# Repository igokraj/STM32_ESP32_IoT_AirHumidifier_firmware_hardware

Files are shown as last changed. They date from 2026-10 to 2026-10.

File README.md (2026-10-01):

# STM32 + ESP32 IoT (AWS Core) Air Humidifier

Projekt zakładał stworzenie sterownika nawilżacza powietrza opartego na dwóch mikrokontrolerach STM32F446RE oraz ESP32-S3. STM32 odpowiada za sterowanie wentylatorem sygnałem PWM, obsługę czujników oraz maszynę stanów, na której opiera się działanie systemu. ESP32 służy wyłącznie do połączenia urządzenia z Wi-Fi, a następnie chmurą AWS IoT Core (Amazon) poprzez protokół MQTT.

Oba mikrokontrolery komunikują się ze sobą przez UART, wymieniając wiadomości w formacie JSON. STM32 wysyła do ESP32 informacje o aktualnej wilgotności, stanie systemu, prędkości obrotowej wentylatora oraz progu wilgotności ustawionym przez użytkownika. ESP32 przekazuje do STM32 wiadomość JSON przygotowaną wcześniej przez użytkownika, zawierającą żądany próg wilgotności w pomieszczeniu (np. 60%) oraz żądaną prędkość wentylatora, wybieraną poziomami od 0 do 5. Każdy poziom odpowiada innemu wypełnieniu sygnału PWM.

Firmware na STM32 jest napisany w C++, natomiast ESP32 działa na FreeRTOS, który jest natywną częścią frameworka.

Projekt był testowany na płytce stykowej, bez rzeczywistego wentylatora. Pomiar prędkości obrotowej sprawdzałem za pomocą drugiego timera, który generował impulsy i był fizycznie połączony z wejściem timera zliczającego impulsy z wentylatora. Sterowanie wentylatorem testowałem na servo ze zmienionymi parametrami sygnału PWM, ale logika sterowania pozostała taka sama.

This is an air humidifier controller built around two microcontrollers: an STM32F446RE and an ESP32-S3. The STM32 does the actual work. It drives the fan with PWM, reads the sensors and runs the state machine the whole system is based on. The ESP32 has only one job: it connects to Wi-Fi and talks to AWS IoT Core over MQTT.

The two chips talk to each other over UART using JSON messages. The STM32 sends the current humidity, system state, fan RPM and the humidity target set by the user. The ESP32 sends back a JSON message from the user with the target room humidity (e.g. 60%) and the fan speed level, from 0 to 5. Each level is a different PWM duty cycle.

The STM32 firmware is written in C++. The ESP32 runs on FreeRTOS, which comes built into ESP-IDF.

I tested everything on a breadboard without a real fan. To check the RPM measurement, I used a second timer to generate pulses and wired it to the input of the timer that counts the fan pulses. For fan control I used a servo instead, with different PWM settings, but the control logic stayed the same.

## Photos

**Breadboard prototype**

<p align="center">
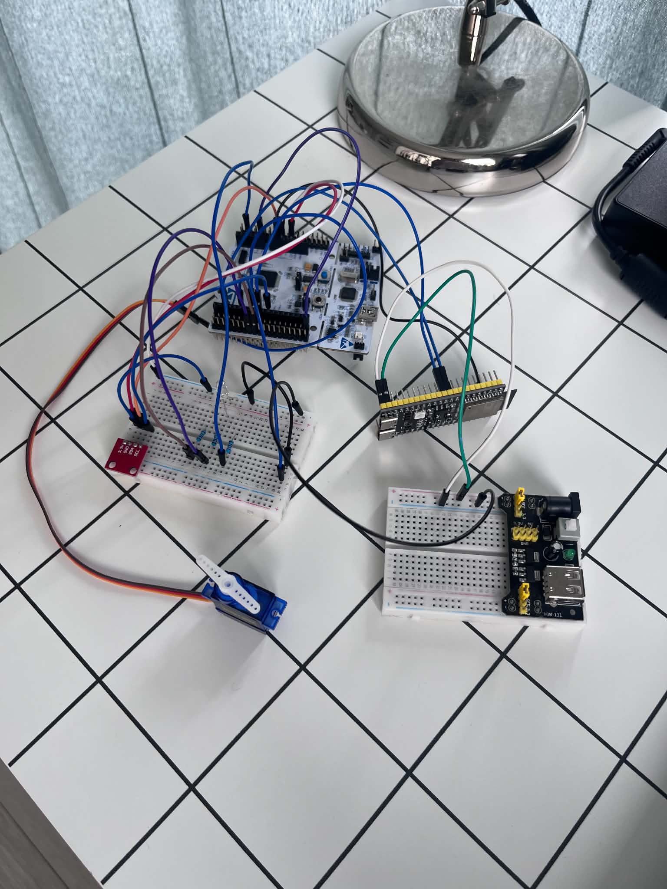
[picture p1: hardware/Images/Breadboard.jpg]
  
</p>

**Schematic**

<p align="center">
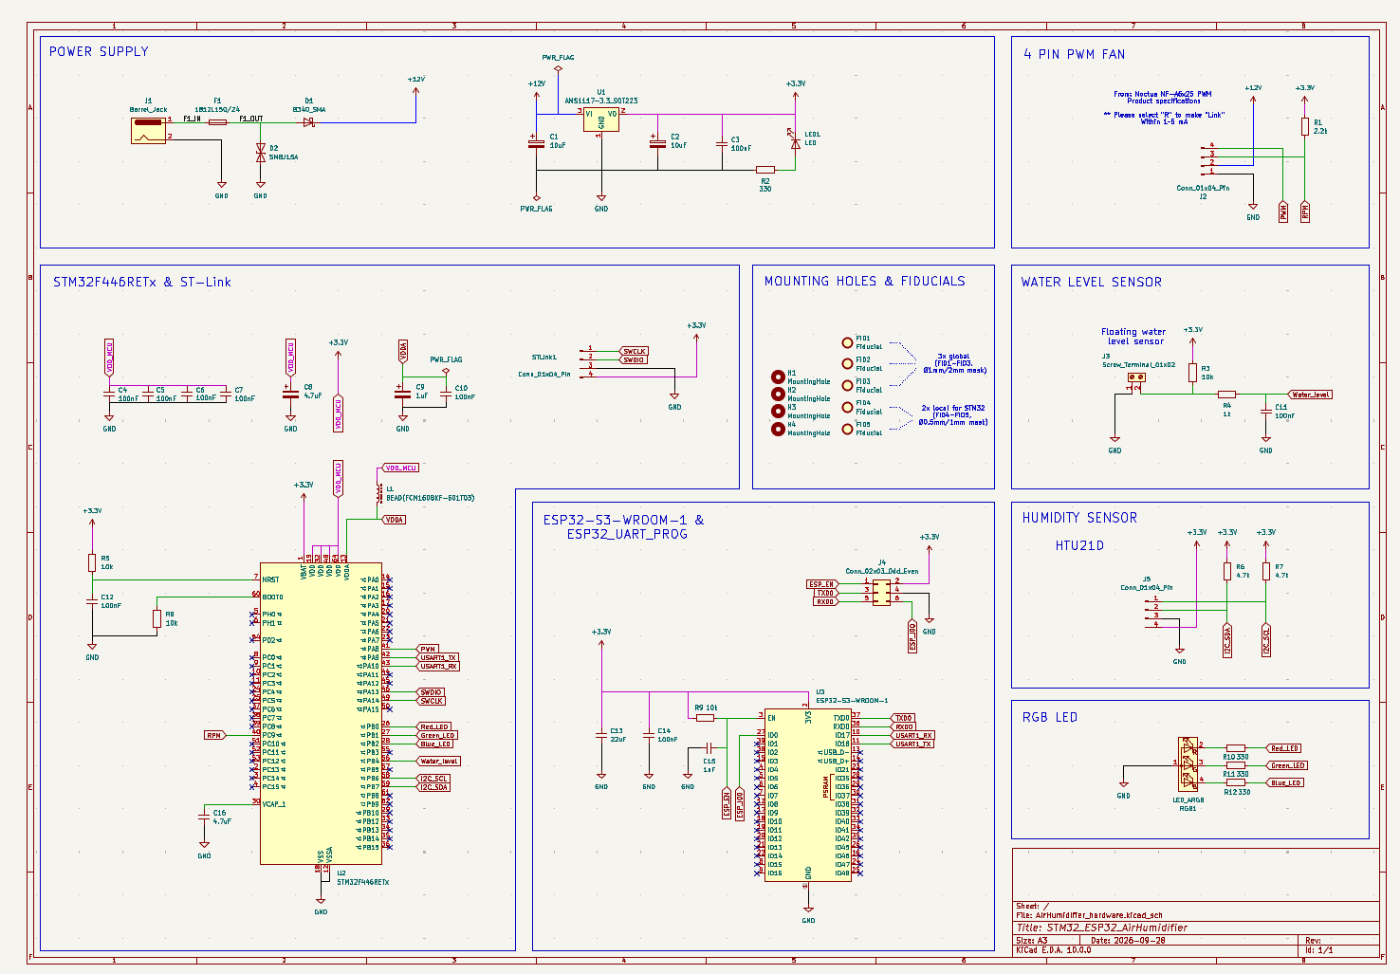
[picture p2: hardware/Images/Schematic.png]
  
</p>

**PCB layout and 3D render**

<p align="center">
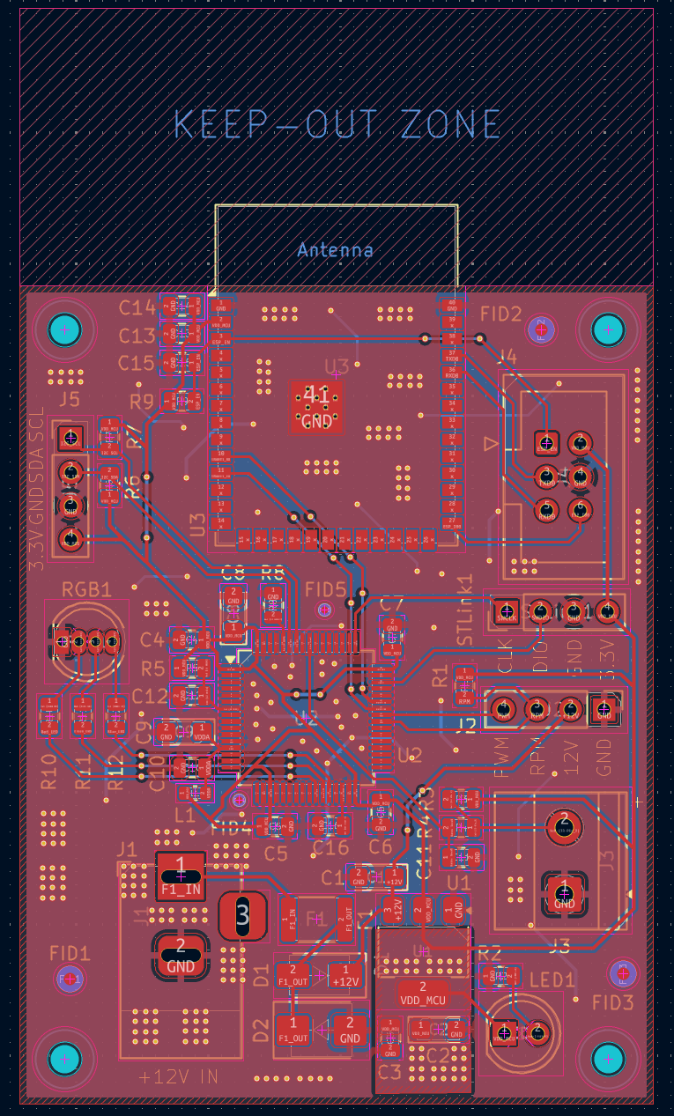
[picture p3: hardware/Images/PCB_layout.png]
  
  &nbsp;
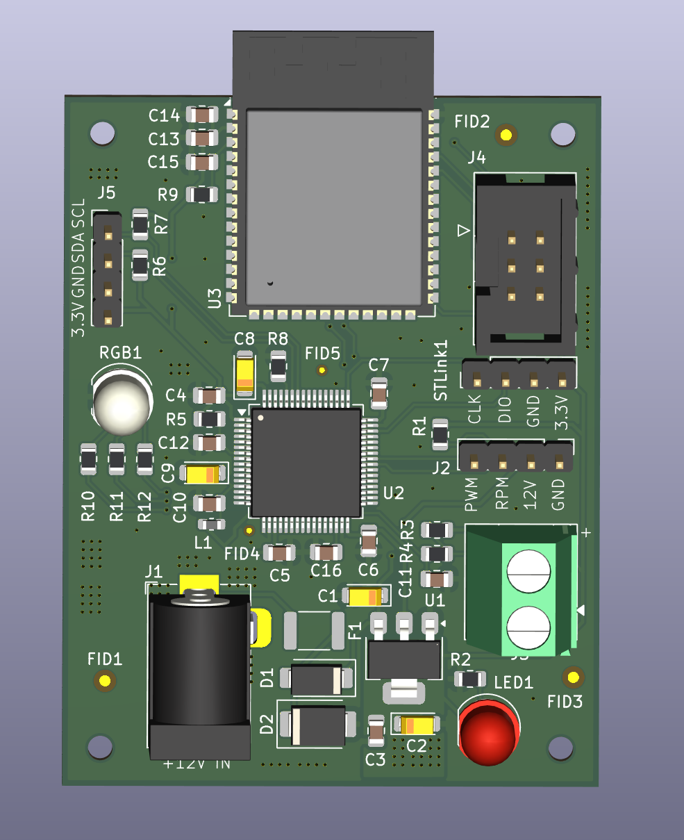
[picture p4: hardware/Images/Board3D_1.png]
  
</p>

<p align="center">
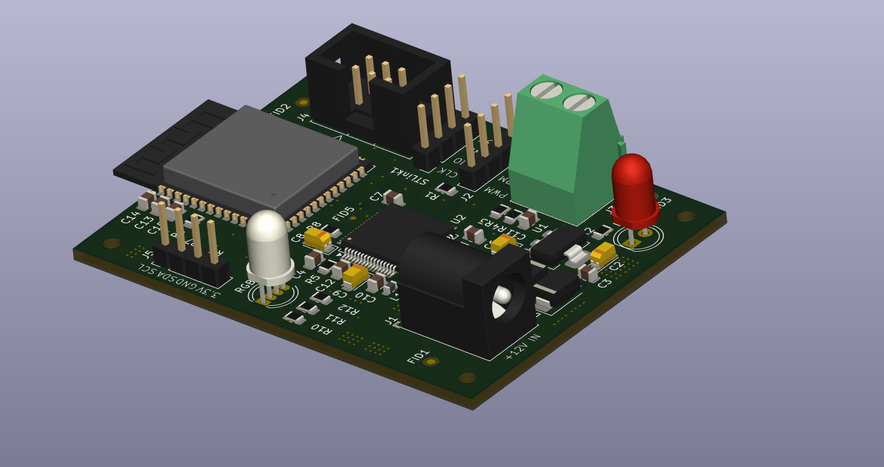
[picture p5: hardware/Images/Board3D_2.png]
  
</p>

## How it works

The system has four states: **Waiting**, **Running**, **EmptyContainer** (no water in the tank) and **Error**.

In the main loop the STM32:

1. checks for a JSON command from the ESP32 (`{"hum": 55, "rpm_lvl": 3}`) and updates the target humidity and fan speed level,
2. reads humidity from the HTU21D every 1 s. After 3 failed reads in a row it resets the I2C bus and goes into Error,
3. reads the water level sensor (float switch),
4. sets the state. Priority: sensor fault, then empty tank, then humidity below target,
5. drives the fan (PWM) and the RGB LED (green: running, blue: empty tank, red: error),
6. every 10 s sends a status message to the ESP32, for example `{"CurrentHumidity":48.20,"SetHum":70.00,"Status":1,"RPM":2000}`.

Fan speed has 6 levels (0 to 5, which means 0 to 100% PWM). The real RPM is measured from the fan's tachometer output using timer input capture. The watchdog (IWDG) resets the MCU if the program hangs.

The ESP32 passes messages between UART (115200 baud) and MQTT (TLS):

- publishes to `humidifier/<client_id>/data`
- subscribes to `humidifier/<client_id>/cmd` (only valid JSON is sent on to the STM32)

## Peripherals / electronics

- **STM32F446RETx**: main microcontroller
- **ESP32-S3-WROOM-1**: Wi-Fi / MQTT module
- **HTU21D**: humidity sensor (I2C)
- **4-pin PWM fan** (PC fan, e.g. Noctua NF-A6x25 PWM): 12 V, PWM and tachometer
- **Water level sensor** (float switch)
- **RGB LED**: shows the system state
- **AMS1117-3.3**: 3.3 V voltage regulator
- 12 V power connector (barrel jack) with a fuse, reverse polarity diode and TVS overvoltage protection
- SWD connector (ST-Link) for the STM32 and UART/boot header for programming the ESP32

## BOM (short version)

| Reference | Component | Qty |
| --- | --- | --- |
| U2 | STM32F446RETx | 1 |
| U3 | ESP32-S3-WROOM-1 | 1 |
| U1 | AMS1117-3.3 (3.3 V regulator) | 1 |
| RGB1 | RGB LED | 1 |
| LED1 | LED (power indicator) | 1 |
| J1 | Power jack (barrel jack) | 1 |
| J2 | 4-pin PWM fan connector | 1 |
| J3 | Screw terminal (water level sensor) | 1 |
| J4 | ESP32 programming header | 1 |
| J5 | HTU21D connector | 1 |
| STLink1 | STM32 programmer connector | 1 |
| F1 | Fuse | 1 |
| D1 | Schottky diode B340 (reverse polarity protection) | 1 |
| D2 | TVS diode SMBJ15A (overvoltage protection) | 1 |
| L1 | Ferrite bead (power filtering) | 1 |
| R, C | Resistors and capacitors (filtering, pull-up/down) | ~28 |

The full list (with LCSC part numbers) is in `AirHumidifier/hardware/BOM.xlsx` and `All_BOM.csv`.

## Firmware

**STM32**: written in **C++** on top of the C code generated by STM32CubeMX/HAL. The humidifier state logic, humidity sensor, UART, JSON parser and I2C bus recovery are separate classes/modules. The rest (GPIO, I2C, timers, UART, watchdog) is generated HAL code.

**ESP32**: written in **C** with ESP-IDF (FreeRTOS), split into `WIFI`, `UART` and `MQTT` modules. To build it you have to add your own `main/secrets.h` (Wi-Fi credentials, AWS endpoint and client ID) and AWS IoT certificates in `main/Cert/`. They are not included in the repo.

## Repo structure

- `AirHumidifier/firmware/stm32/`: CMake project with the STM32 sources
- `AirHumidifier/firmware/esp32/`: ESP-IDF project for the ESP32
- `AirHumidifier/hardware/`: KiCad schematic and PCB, production files (Gerbers), BOM
- `AirHumidifier/hardware/Images/`: schematic and PCB renders

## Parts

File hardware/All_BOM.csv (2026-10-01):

Reference | Qty | Value | DNP | Exclude from BOM | Exclude from Board | Footprint | Datasheet
C1,C2 | 2 | 10uF |  |  |  | Capacitor_Tantalum_SMD:CP_EIA-3216-18_Kemet-A
C3,C4,C5,C6,C7,C10,C11,C12,C14 | 9 | 100nF |  |  |  | Capacitor_SMD:C_0805_2012Metric
C8 | 1 | 4.7uF |  |  |  | Capacitor_Tantalum_SMD:CP_EIA-3216-18_Kemet-A
C9 | 1 | 1uF |  |  |  | Capacitor_Tantalum_SMD:CP_EIA-3216-18_Kemet-A
C13 | 1 | 22uF |  |  |  | Capacitor_SMD:C_0805_2012Metric
C15 | 1 | 1uF |  |  |  | Capacitor_SMD:C_0805_2012Metric
C16 | 1 | 4.7uF |  |  |  | Capacitor_SMD:C_0805_2012Metric
D1 | 1 | B340_SMA |  |  |  | Diode_SMD:D_SMA
D2 | 1 | SMBJ15A |  |  |  | Diode_SMD:D_SMB
F1 | 1 | 1812L150/24 |  |  |  | Fuse:Fuse_1812_4532Metric
J1 | 1 | Barrel_Jack |  |  |  | Connector_BarrelJack:BarrelJack_Horizontal
J2,J5,STLink1 | 3 | Conn_01x04_Pin |  |  |  | Connector_PinHeader_2.54mm:PinHeader_1x04_P2.54mm_Vertical
J3 | 1 | Screw_Terminal_01x02 |  |  |  | TerminalBlock_Phoenix:TerminalBlock_Phoenix_MKDS-1,5-2-5.08_1x02_P5.08mm_Horizontal
J4 | 1 | Conn_02x03_Odd_Even |  |  |  | Connector_IDC:IDC-Header_2x03_P2.54mm_Vertical
L1 | 1 | BEAD(FCM1608KF-601T03) |  |  |  | Inductor_SMD:L_0603_1608Metric
LED1 | 1 | LED |  |  |  | LED_THT:LED_D5.0mm
R1 | 1 | 2.2k |  |  |  | Resistor_SMD:R_0805_2012Metric
R2,R10,R11,R12 | 4 | 330 |  |  |  | Resistor_SMD:R_0805_2012Metric
R3,R5,R8,R9 | 4 | 10k |  |  |  | Resistor_SMD:R_0805_2012Metric
R4 | 1 | 1k |  |  |  | Resistor_SMD:R_0805_2012Metric
R6,R7 | 2 | 4.7k |  |  |  | Resistor_SMD:R_0805_2012Metric
RGB1 | 1 | LED_ARGB |  |  |  | LED_THT:LED_D5.0mm-4_RGB
U1 | 1 | AMS1117-3.3_SOT223 |  |  |  | Package_TO_SOT_SMD:SOT-223-3_TabPin2 | http://www.advanced-monolithic.com/pdf/ds1117.pdf
U2 | 1 | STM32F446RETx |  |  |  | Package_QFP:LQFP-64_10x10mm_P0.5mm | https://www.st.com/resource/en/datasheet/stm32f446re.pdf
U3 | 1 | ESP32-S3-WROOM-1 |  |  |  | RF_Module:ESP32-S3-WROOM-1 | https://www.espressif.com/sites/default/files/documentation/esp32-s3-wroom-1_wroom-1u_datasheet_en.pdf

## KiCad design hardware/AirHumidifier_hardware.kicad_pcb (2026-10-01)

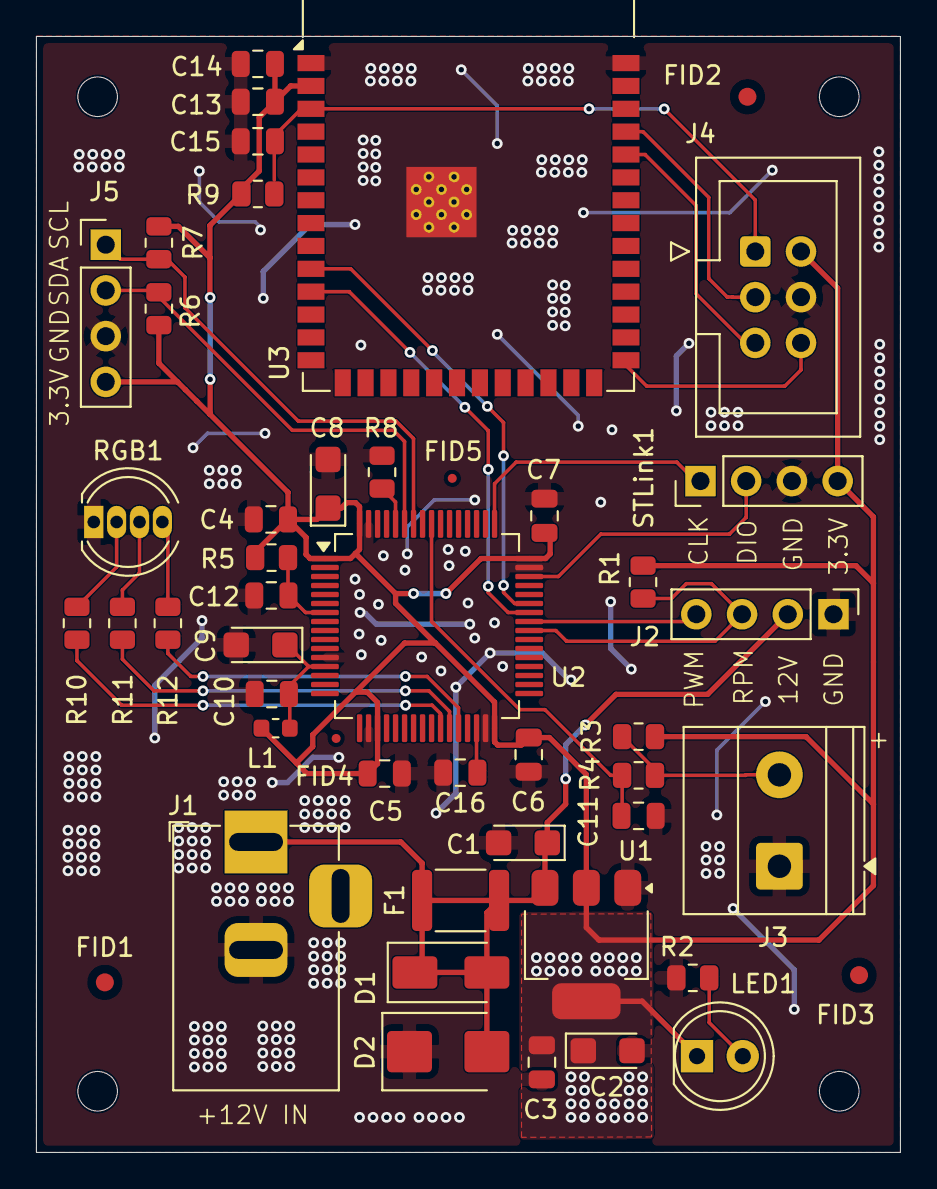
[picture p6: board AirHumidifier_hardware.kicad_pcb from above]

Board: 2 copper layers, 48.0 x 62.0 mm, 52 parts (0 on the bottom side), 28 nets.

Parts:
C1, C2: 10uF; CP_EIA-3216-18_Kemet-A
C3, C4, C5, C6, C7, C10, C11, C12, C14: 100nF; C_0805_2012Metric
C8: 4.7uF; CP_EIA-3216-18_Kemet-A
C9: 1uF; CP_EIA-3216-18_Kemet-A
C13: 22uF; C_0805_2012Metric
C15: 1uF; C_0805_2012Metric
C16: 4.7uF; C_0805_2012Metric
D1: B340_SMA; D_SMA
D2: SMBJ15A; D_SMB
F1: 1812L150/24; Fuse_1812_4532Metric
FID1, FID2, FID3: Fiducial; Fiducial_1mm_Mask2mm
FID4, FID5: Fiducial; Fiducial_0.5mm_Mask1mm
H1, H2, H3, H4: MountingHole; MountingHole_2.2mm_M2
J1: Barrel_Jack; BarrelJack_Horizontal
J2, J5: Conn_01x04_Pin; PinHeader_1x04_P2.54mm_Vertical
J3: Screw_Terminal_01x02; TerminalBlock_Phoenix_MKDS-1,5-2-5.08_1x02_P5.08mm_Horizont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
J4: Conn_02x03_Odd_Even; IDC-Header_2x03_P2.54mm_Vertical
L1: BEAD(FCM1608KF-601T03); L_0603_1608Metric
LED1: LED; LED_D5.0mm
R1: 2.2k; R_0805_2012Metric
R2, R10, R11, R12: 330; R_0805_2012Metric
R3, R5, R8, R9: 10k; R_0805_2012Metric
R4: 1k; R_0805_2012Metric
R6, R7: 4.7k; R_0805_2012Metric
RGB1: LED_ARGB; LED_D5.0mm-4_RGB
STLink1: Conn_01x04_Pin; PinHeader_1x04_P2.54mm_Vertical
U1: AMS1117-3.3_SOT223; SOT-223-3_TabPin2
U2: STM32F446RETx; LQFP-64_10x10mm_P0.5mm
U3: ESP32-S3-WROOM-1

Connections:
+12V: C1.1, D1.1 (K), D1.2 (A), D2.2 (A2), F1.1, F1.2, J1.1, J2.2, U1.3 (VI)
Blue_LED: R12.2, U2.28 (PB2)
ESP_EN: C15.1, J4.1, R9.2, U3.3 (EN)
ESP_I00: J4.6, U3.27 (IO0)
GND: C1.2, C2.2, C3.2, C4.2, C5.2, C6.2, C7.2, C8.2, C9.2, C10.2, C11.2, C12.2, C13.2, C14.2, C15.2, C16.2, D2.1 (A1), J1.2, J2.1, J3.1, J4.4, J5.3, R2.1, R8.1, RGB1.1 (A), STLink1.3, U1.1 (GND), U2.12 (VSSA), U2.18 (VSS), U2.31 (VSS), U2.47 (VSS), U2.63 (VSS), U3.1 (GND), U3.40 (GND), U3.41 (GND)
Green_LED: R11.2, U2.27 (PB1)
I2C_SCL: J5.1, R7.2, U2.58 (PB6)
I2C_SDA: J5.2, R6.2, U2.59 (PB7)
unnamed: J3.2, R3.2, R4.1
unnamed: LED1.2 (A), R2.2
unnamed: R12.1, RGB1.4 (BK)
unnamed: R11.1, RGB1.3 (GK)
unnamed: R10.1, RGB1.2 (RK)
unnamed: R8.2, U2.60 (BOOT0)
unnamed: C12.1, R5.2, U2.7 (NRST)
unnamed: C16.1, U2.30 (VCAP_1)
PWM: J2.4, U2.41 (PA8)
RPM: J2.3, R1.2, U2.40 (PC9)
RXD0: J4.5, U3.36 (RXD0)
Red_LED: R10.2, U2.26 (PB0)
SWCLK: STLink1.1, U2.49 (PA14)
SWDIO: STLink1.2, U2.46 (PA13)
TXD0: J4.3, U3.37 (TXD0)
USART1_RX: U2.43 (PA10), U3.10 (IO17)
USART1_TX: U2.42 (PA9), U3.11 (IO18)
VDDA: C9.1, C10.1, L1.2, U2.13 (VDDA)
VDD_MCU: C2.1, C3.1, C4.1, C5.1, C6.1, C7.1, C8.1, C13.1, C14.1, J4.2, J5.4, L1.1, LED1.1 (K), R1.1, R3.1, R5.1, R6.1, R7.1, R9.1, STLink1.4, U1.2 (VO), U2.1 (VBAT), U2.19 (VDD), U2.32 (VDD), U2.48 (VDD), U2.64 (VDD), U3.2 (3V3)
Water_level: C11.1, R4.2, U2.56 (PB4)

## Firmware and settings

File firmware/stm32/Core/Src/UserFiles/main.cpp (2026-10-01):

#include "main.hpp"
#include "stm32f4xx_hal.h"
#include "main.h"
#include "i2c.h"
#include "iwdg.h"
#include "tim.h"
#include "usart.h"
#include "uart.hpp"

// User files
#include "jsonParser.hpp"
#include "humiditySensor.hpp"
#include "digital_output.hpp"
#include "I2C_recovery.hpp"


#define TIM1_ARR 3359
#define UART_MSG_DELAY 10000
#define HTU21D_DELAY 1000


// Desired RPM_lvl;
int lvl = 0;

enum class SystemStatus_t {
    Waiting,
    Running,
    EmptyContainer,
    Error
};

// Global, because the HAL callbacks below need to reach it
Uart espUart(&huart1);

extern "C" void HAL_UART_RxCpltCallback(UART_HandleTypeDef *huart) {
    if (huart == espUart.handle()) espUart.onByte();
}

// Overrun or noise stops the reception, so start it again
extern "C" void HAL_UART_ErrorCallback(UART_HandleTypeDef *huart) {
    if (huart == espUart.handle()) espUart.Receive();
}


#define TIM3_TICK_HZ        100000u   // 84 MHz / (839 + 1) -> 1 tick = 10 us
#define FAN_PULSES_PER_REV  2u        // check in the fan datasheet, most PC fans give 2
#define FAN_STOP_TIMEOUT_MS 500u      // no pulse for this long -> fan stopped

// Values from the TIM3 interrupt in main.c USER BEGIN 4
extern volatile uint32_t lastPulseTime;
extern volatile uint32_t period;

uint16_t CalculateRPM() {

    // Copy the values, so both come from the same moment
    uint32_t p = period;
    uint32_t last = lastPulseTime;

    // Return 0 if there are no pulses, or the microcontroller hasn't seen one for FAN_STOP_TIMEOUT_MS
    if (p == 0 || (HAL_GetTick() - last > FAN_STOP_TIMEOUT_MS)) {
        return 0;
    }

    // Calculate the RPM
    return (60u * TIM3_TICK_HZ) / (p * FAN_PULSES_PER_REV);
}


/*
RPM_lvl  |  PWM (%)   |  RPM
0        |  0         |  0
1        |  20        |  700
2        |  40        |  1400
3        |  60        |  2000
4        |  80        |  2600
5        |  100       |  3000
*/
uint32_t SetPWM(uint16_t RPM_lvl) {

    return (TIM1_ARR + 1) * RPM_lvl / 5;
}

DigitalOutput RedLed(Red_LED_GPIO_Port, Red_LED_Pin);
DigitalOutput GreenLed(Green_LED_GPIO_Port, Green_LED_Pin);
DigitalOutput BlueLed(Blue_LED_GPIO_Port, Blue_LED_Pin);

void ApplyOutPuts(SystemStatus_t Status) {
    switch (Status) {
        case SystemStatus_t::Waiting:
        __HAL_TIM_SET_COMPARE(&htim1, TIM_CHANNEL_1, 0);
            RedLed.off();
            BlueLed.off();
            GreenLed.off();
            break;
        case SystemStatus_t::Running:
        __HAL_TIM_SET_COMPARE(&htim1, TIM_CHANNEL_1, SetPWM(lvl));
            RedLed.off();
            BlueLed.off();
            GreenLed.on();
            break;
        case SystemStatus_t::EmptyContainer:
        __HAL_TIM_SET_COMPARE(&htim1, TIM_CHANNEL_1, 0);
            RedLed.off();
            BlueLed.on();
            GreenLed.off();
            break;
        case SystemStatus_t::Error:
        __HAL_TIM_SET_COMPARE(&htim1, TIM_CHANNEL_1, 0);
            RedLed.on();
            BlueLed.off();
            GreenLed.off();
            break;
    }
}


class Humidifier {

public:
    Humidifier(float desiredHum) : desiredHum_(desiredHum) {}

    // Getters
    SystemStatus_t getSystemStatus() const {
        return systemStatus_;
    }

    float getDesiredHum() const {
        return desiredHum_;
    }

    // Setters
    void setCurrentHum(float currentHum) {
        currentHum_ = currentHum;
    }

    void setDesiredHum(float desiredHum) {
        desiredHum_ = desiredHum;
    }

    void setContainerEmpty(bool containerEmpty) {
        containerEmpty_ = containerEmpty;
    }

    void setSensorFailed(bool sensorFailed) {
        sensorFailed_ = sensorFailed;
    }

    
    void updateStatus() {

        if (sensorFailed_) {
            systemStatus_ = SystemStatus_t::Error;
            return;
        }

        if (containerEmpty_) {
            systemStatus_ = SystemStatus_t::EmptyContainer;
            return;
        }

        if (currentHum_ < desiredHum_) {
            systemStatus_ = SystemStatus_t::Running;
        }
        else if (currentHum_ >= desiredHum_) {
            systemStatus_ = SystemStatus_t::Waiting;
        }

    }

    private:
    float currentHum_ = 0.0f;   // measured humidity [%]
    float desiredHum_;          // setpoint humidity [%]

    // Init these as false
    bool containerEmpty_ = false;
    bool systemFailed_ = false;
    bool sensorFailed_ = false;

    // Initial status: Waiting
    SystemStatus_t systemStatus_ = SystemStatus_t::Waiting;
};



void app_main() {

    // Delays
    uint32_t last_uart_mag = 0;
    uint32_t last_htu21d_mag = HAL_GetTick() - HTU21D_DELAY - 1; // Let the first measurement start right after the start

    // Current hum given by HTU21D.
    // Passed -1.0f so the program never uses a random value before the first measurement. -1.0f means "no valid reading".
    float hum = -1.0f;

    Humidifier AirHumidifier(70.0f); // Set initial desired humidity to 70%
    HumiditySensor HTU21D(&hi2c1, 0x40); 
    uint8_t sensorFails = 0; // counter of the incorrect htu21d hum values

    espUart.Receive();   // arm the first byte, the interrupt does the rest

    while (1) {
    

// Wait for a JSON message and, once it's ready, parse it into variables (hum and rpm_lvl)

if (espUart.hasLine()) {

    if (auto hum = jsonNumber(espUart.line(), "hum")) {
        if (*hum >= 0.0f && *hum <= 100.0f) {
            AirHumidifier.setDesiredHum(*hum);
        }
    }

    if (auto rpm_lvl = jsonNumber(espUart.line(), "rpm_lvl")) {
        lvl = static_cast<int>(*rpm_lvl);
        if (lvl > 5) {
            lvl = 5;
        }
        else if (lvl < 0) {
            lvl = 0;
        }
    }

    espUart.release();   // Release the buffer so the UART can receive another message
}

        uint32_t now_htu21d = HAL_GetTick();
        // Read the current humidity (set sensorFailed if the reading is invalid, clear it otherwise)
        if (now_htu21d - last_htu21d_mag > HTU21D_DELAY) {
        hum = HTU21D.readHumidity();
        if (hum == -1.0f) {
            if (sensorFails < 3) {
            sensorFails += 1;
            if (sensorFails == 3) {
                // This function is used to recover a jammed I2C bus during normal program operation (not after a restart).
                I2C1_Reinit();         
                sensorFails = 0;
                AirHumidifier.setSensorFailed(true);
            }
        }
        }
        else {
            sensorFails = 0;
            AirHumidifier.setCurrentHum(hum);
            AirHumidifier.setSensorFailed(false);
        }
        last_htu21d_mag = now_htu21d;
    }
     
        // Read the water level
        if (HAL_GPIO_ReadPin(Water_level_GPIO_Port, Water_level_Pin) == GPIO_PIN_SET) {
        AirHumidifier.setContainerEmpty(true);
        }
        else {
            AirHumidifier.setContainerEmpty(false);
        } 
        
        // Update system status according to the readings above
        AirHumidifier.updateStatus();

        // Apply outputs according to the current system status
        ApplyOutPuts(AirHumidifier.getSystemStatus());

        // Send a message to the ESP32 with the system's current characteristics
        uint32_t now_uart = HAL_GetTick();
        if (now_uart - last_uart_mag > UART_MSG_DELAY) {
        espUart.Send(hum, AirHumidifier.getDesiredHum(), static_cast<int>(AirHumidifier.getSystemStatus()), CalculateRPM());
        last_uart_mag = now_uart;
        }

        HAL_IWDG_Refresh(&hiwdg);

    }
}

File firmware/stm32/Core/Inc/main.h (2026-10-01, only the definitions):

#define B1_Pin GPIO_PIN_13
#define B1_GPIO_Port GPIOC
#define USART_TX_Pin GPIO_PIN_2
#define USART_TX_GPIO_Port GPIOA
#define USART_RX_Pin GPIO_PIN_3
#define USART_RX_GPIO_Port GPIOA
#define LD2_Pin GPIO_PIN_5
#define LD2_GPIO_Port GPIOA
#define Red_LED_Pin GPIO_PIN_0
#define Red_LED_GPIO_Port GPIOB
#define Green_LED_Pin GPIO_PIN_1
#define Green_LED_GPIO_Port GPIOB
#define Blue_LED_Pin GPIO_PIN_2
#define Blue_LED_GPIO_Port GPIOB
#define RPM_Pin GPIO_PIN_9
#define RPM_GPIO_Port GPIOC
#define PWM_Pin GPIO_PIN_8
#define PWM_GPIO_Port GPIOA
#define TMS_Pin GPIO_PIN_13
#define TMS_GPIO_Port GPIOA
#define TCK_Pin GPIO_PIN_14
#define TCK_GPIO_Port GPIOA
#define SWO_Pin GPIO_PIN_3
#define SWO_GPIO_Port GPIOB
#define Water_level_Pin GPIO_PIN_4
#define Water_level_GPIO_Port GPIOB

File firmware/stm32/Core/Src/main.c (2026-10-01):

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
/* Includes ------------------------------------------------------------------*/
#include "main.h"
#include "i2c.h"
#include "iwdg.h"
#include "tim.h"
#include "usart.h"
#include "gpio.h"

/* USER CODE BEGIN Includes */
#include "main.hpp"
#include "I2C_recovery.hpp"
/* USER CODE END Includes */


void SystemClock_Config(void);
/**
  * @brief  The application entry point.
  * @retval int
  */
int main(void)
{

  /* MCU Configuration--------------------------------------------------------*/

  /* Reset of all peripherals, Initializes the Flash interface and the Systick. */
  HAL_Init();

  /* Configure the system clock */
  SystemClock_Config();

  /* USER CODE BEGIN SysInit */
  I2C1_BusRecovery();
  /* USER CODE END SysInit */

  /* Initialize all configured peripherals */
  MX_GPIO_Init();
  MX_IWDG_Init();
  MX_USART1_UART_Init();
  MX_USART2_UART_Init();
  MX_I2C1_Init();
  MX_TIM1_Init();
  MX_TIM3_Init();
  /* USER CODE BEGIN 2 */
  HAL_TIM_IC_Start_IT(&htim3, TIM_CHANNEL_4);
  HAL_TIM_PWM_Start(&htim1, TIM_CHANNEL_1);
  app_main();
  /* USER CODE END 2 */

  /* Infinite loop */
  /* USER CODE BEGIN WHILE */
  while (1)
  {
    /* USER CODE END WHILE */

    /* USER CODE BEGIN 3 */
  }
  /* USER CODE END 3 */
}

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
/* USER CODE BEGIN 4 */

// Timer tick -> 1 tick = 10 us

volatile uint32_t lastCapture = 0;    // (ticks)
volatile uint32_t lastPulseTime = 0;  // time of the last pulse (ms)
volatile uint32_t period = 0;         // time between the last two pulses (ticks)
// If for example period -> 6000 ticks that means that 60000 us had passed, which is 0.06 s

extern "C" void HAL_TIM_IC_CaptureCallback(TIM_HandleTypeDef *htim) {
  if (htim->Instance == TIM3 && htim->Channel == HAL_TIM_ACTIVE_CHANNEL_4) {

    // Detects timer value from 0 - 65535 (0xFFFF)
    uint32_t now = HAL_TIM_ReadCapturedValue(htim, TIM_CHANNEL_4);

    /* Ticks since the previous pulse. The 0xFFFF mask keeps the result correct even if
    the 16-bit counter wrapped around between the two pulses. Example:
    60000 ... 65535 -> 0 ... 500, so period = (65536 - 60000) + 500 = 6036 ticks */
    period = (now - lastCapture) & 0xFFFF;

    // Remember this pulse for the next calculation
    lastCapture = now;

    // Remember when the pulse arrived, so the main loop knows the fan is still spinning
    lastPulseTime = HAL_GetTick();
  }
}
/* USER CODE END 4 */
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


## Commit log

2026-09-25 First commit, added .gitignore configuration, added simple UART echo task
2026-09-25 Implemented reception and verification JSON data and sending it forward to the stm32
2026-09-25 Implemented reception and verification JSON data send by STM32 to the ESP32 and to the AWS broker via MQTT
    [main.c, mqtt.c, uart.c]
2026-09-25 Added container watter level update and sensorFailed update in the main loop
2026-09-25 Added UART receive JSON data from esp32 funcionality to handle desired humidity and rpm
2026-09-25 Added PWM values control by the desiredRpm value. To do -> Assign RPM values to five levels and control them for greater clarity
2026-09-26 Refactored PWM control to use logic levels from 0-5
2026-09-26 Added function which sends the JSON data format to ESP32
2026-09-26 Changed I2C pins, added Send function delay
2026-09-26 RPM calucaltion and ticks detecion Passed with the help of other timer -> TIM2 with PWM for tesitng
2026-09-27 JSON data receive (rpm_lvl) from ESP32 Passed
2026-09-27 JSON data receive (hum) from ESP32 Passed
2026-09-27 Added SetHum to the message from STM32 to ESP32 message, Conectivity test bewteen stm and esp Passed. TO DO -> Handle the problem with I2C bus hang after microcontroler reset
    [STM32_ESP32_AirHumidifier.ioc, main.cpp]
2026-09-27 Fixed the bug with stuck I2C by adding I2C1_BusRecovery function which restores I2C to the default state after microcontroler reset, deleted fragments of test purpose code
    [I2C_recovery.cpp, main.c, main.cpp]
2026-09-27 Added RGB LED to signal status of the system
2026-09-27 Fixed the bug with jaming I2C line after quick connecting/disconeccting power or SDA/SCL lines on HTU21D
    [I2C_recovery.cpp, main.cpp]
2026-09-28 Put the I2C1_BusRecovery() in the right place in main.c
2026-10-01 Add hardware (KiCad)
    [AirHumidifier_hardware-B_Cu.gbr, AirHumidifier_hardware-B_Mask.gbr, AirHumidifier_hardware-B_Paste.gbr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]

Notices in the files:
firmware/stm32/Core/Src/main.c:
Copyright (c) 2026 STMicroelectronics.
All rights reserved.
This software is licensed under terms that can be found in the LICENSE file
